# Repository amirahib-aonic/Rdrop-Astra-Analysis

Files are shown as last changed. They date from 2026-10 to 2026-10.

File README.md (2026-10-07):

# Rdrop Astra analysis

Three-stage illustrated evaluation: functional review, conservative refinement and complete redesign.

Website: https://amirahib-aonic.github.io/Rdrop-Astra-Analysis/

The four HTML pages use assets/, sources/ and downloads/. Original individual reports are retained in GPT6 Refined/Comparison/ and GPT6 New/Report/.

Hardware files are prototype evidence; automated design checks do not establish flight, functional or thermal qualification.

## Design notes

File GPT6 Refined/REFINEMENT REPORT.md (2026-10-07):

# Rdrop Astra — GPT6 refinement

6 October 2026 • KiCad 9.0.7 • Two copper layers • 1 oz copper target

This is a conservative copper and routing refinement for comparison with the original design. It is **not a verified 15 A / 18S thermal qualification**. The original project in `PCB Design` is unchanged. Open `hw-aonic-r-drop-main-board.kicad_pro` in this folder for the refined design.

## Delivered comparison views

- [Top copper comparison](Comparison/comparison-top.png)
- [Bottom copper comparison](Comparison/comparison-bottom.png) — both shown from above, without mirroring, to make coordinates directly comparable.
- [3D comparison](Comparison/comparison-3d.png)
- [Comparison gallery](Comparison/comparison.html)

Individual PNGs and vector SVGs are included. The images use the same layers, viewpoint, and scale for both designs. 3D views use the existing component models; they are not enclosure-fit or thermal simulations.

## Changes made

| Change | Original | Refined | Reason |
|---|---:|---:|---|
| Main top and bottom GND fill clearance | 0.8 mm | 0.3 mm | Recover ground copper around low-voltage traces and reduce wide return-path gaps. |
| Ground stitching vias | 299 total board vias | 339 total board vias | Add 40 GND vias, 0.8 mm diameter / 0.4 mm drill, in the low-voltage area with copper on both sides. |
| +5V_1 routing | 1.0 mm | 1.5 mm on 12 segments / 77.04 mm | Increase copper cross-section where existing clearances permit. |
| +5V_2 routing | 1.0 mm | 1.5 mm on 6 segments / 27.60 mm | Increase copper cross-section where existing clearances permit. |
| +UBEC_OUT routing | 0.8 mm | 1.2 mm on 4 segments / 9.22 mm | Increase copper cross-section on unconstrained segments. |
| J301 pad 1, GND | Inherited thermal connection | Solid zone connection | Remove an isolated thermal-spoke condition after refilling and give this supply-return pad a direct copper connection. Soldering heat demand increases. |

Seven proposed width increases were rejected after DRC and restored to their original widths. There is no claim that the whole supply path is now 1.5 mm wide. The remaining narrow sections, vias, pads, connectors, and protection parts can still limit current.

The battery-positive zone geometry, its 1.0 mm zone clearance, and its solid pad connections were retained. The dedicated servo-return and current-shunt nets remain separate from GND. USB and CAN signal routing, component placement, antenna keepout, and existing fabrication rules were retained. No components were added or removed; the additions are vias.

## Verification

| Check | Original | Refined |
|---|---:|---:|
| DRC errors | 0 | 0 |
| DRC warnings | 80 | 80 |
| Unconnected items | 0 | 0 |
| Schematic-parity issues | 0 | 0 |
| Footprints, including mounting holes and logos | 78 | 78 |
| Copper layers | 2 | 2 |
| GND filled area, top | 6140.37 mm² | 6876.47 mm² (+12.0%) |
| GND filled area, bottom | 6822.95 mm² | 7399.30 mm² (+8.4%) |

Exact checks verified unchanged footprint identities, values, positions, rotations, sides, pad coordinates, pad sizes, drill sizes, and net assignments. Board outline and cutout geometry are unchanged. All schematic files are byte-identical. The original PCB's SHA-256 remains `c80d10d69f5310de7cd80b0fb0a269ae44d5f7d4dcedefd1dde41fcfe5b25da2`.

The 80 existing warnings comprise 5 footprint-library issues, 40 library mismatches, 4 padstack warnings, 3 silk-edge clearance warnings, 3 silk-over-copper warnings, 10 silk overlaps, 14 text-height warnings, and 1 text-thickness warning. The fuse-pad negative paste margins were retained; they may reflect manual assembly, but that intent has not been confirmed.

Ground area is calculated from KiCad filled polygons, not an electrical performance measurement. No EMI, impedance, voltage-drop, temperature, or functional bench measurements were performed. DRC verifies the configured rules, not suitability of those rules for every operating environment.

## Outstanding current and voltage requirements

The supplied target is 15 A peak, up to an 18S battery, and 15–18 °C maximum temperature rise. Still needed:

1. The exact 15 A path: battery input, servo output, or another connection.
2. Normal current, peak duration, and repetition rate.
3. Confirm the maximum pack voltage: 18 × 4.2 V = 75.6 V if these are 4.2 V cells, versus the stated approximately 72–74 V.

These details are needed before selecting or validating current-carrying neck widths and interpreting the thermal target. Ambient temperature, enclosure cooling, and actual finished copper thickness will also affect measured temperature rise. Retaining the components means their current, voltage, pulse, and power ratings must be considered separately from copper geometry.

## How to compare hardware performance

Use identical assembly, firmware, load waveform, wiring, enclosure, and ambient conditions on both revisions. Measure supply drop and temperature at the same terminals, connectors, fuse/shunt pads, narrow copper sections, and vias. Check current-sense offset/noise, sensor readings, and communication reliability under the same load transitions. A before/after improvement requires those measurements; visual copper changes alone do not establish it.

## Method and records

The board was edited and refilled through the installed KiCad 9.0.7 Python board engine, checked with KiCad 9's DRC and schematic-parity checker, opened for visual review in the KiCad 9 PCB Editor, and rendered with KiCad 9. This was not a mouse-only editing run. `Comparison/changes.json` identifies accepted and rejected edits by UUID; `verification.json` records invariants, counts, areas, and hashes. The scripts document the process; rerunning the initial trial script replaces the refined board with the initial trial, so they are evidence rather than a one-click final-build command.

Ground-return rationale: [TI, PCB trace as a wave guide](https://www.ti.com/video/6307562268112) and [TI, optimizing PCB design for EMC](https://www.ti.com/video/6173428079001). Tool reference: [KiCad 9 zone filler](https://docs.kicad.org/doxygen-python-9.0/classpcbnew_1_1ZONE__FILLER.html).

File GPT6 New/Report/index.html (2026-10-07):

Hardware design report · Revision A · 06 October 2026

# One board. Two supply choices.

A complete two-layer ESP32 controller for the Rdrop drone attachment, preserving the original outline, cutout, mounting centers, magnetic sensor center and optical pad positions.

Prototype handoff · electrical checks passed

KiCad projectFabrication pack ↓

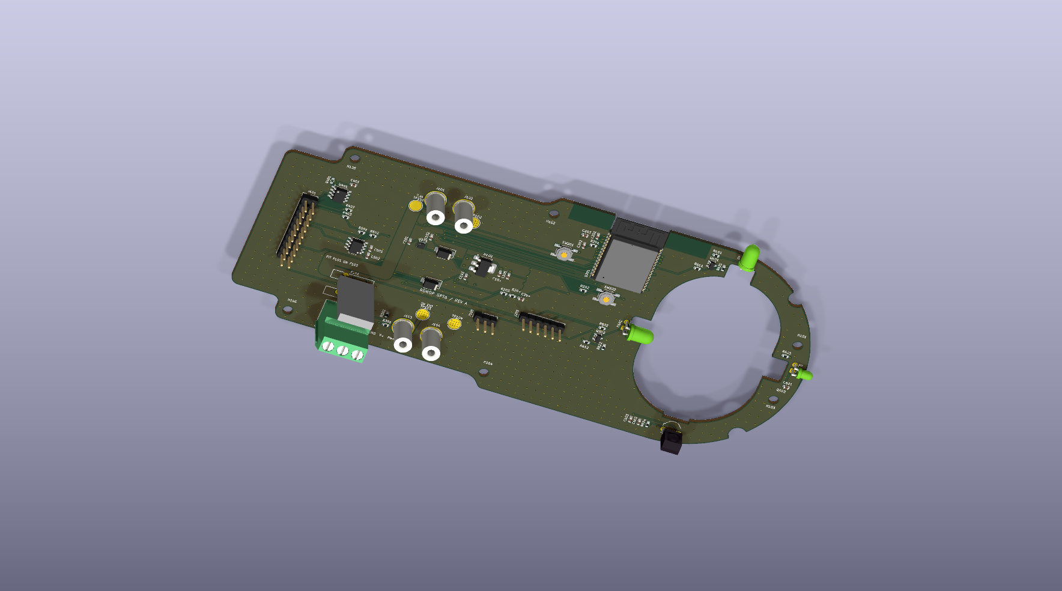
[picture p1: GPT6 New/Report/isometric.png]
Actual KiCad 3D rendering of the Rdrop redesigned PCB


Actual KiCad model · variant A · fuse shown as a conservative body envelope.

0ERC violations

0DRC errors / unrouted nets

2 ozCopper on each of two layers

69Footprints, including board features

The selected protection takes priority over pulse endurance. MF-RG900-0 has 9 A hold and 15.3 A trip specifications at 23 °C. It may interrupt the requested 15 A / 30 second servo pulse. Its trip is thermal and depends on ambient temperature, mounting, load history and airflow. This is the protection option you selected; successful pulse endurance is not guaranteed.

01 / System

## The original functions, rebuilt.

Six functional sheets plus a system sheet. On-board inputs are regulated 7.4 V and 5 V only; a 14–18S battery must stay upstream of an appropriately rated external regulator.

### Logic power

TLV76750DRVR converts 7.4 V to 5 V for logic. Two SS14 diodes combine that output and external 5 V. TLV1117LV33DCYR supplies 3.3 V with ceramic 0603 input/output decoupling.

The AMS1117 alternative remains an LDO, not a switching step-down regulator. TLV1117LV was selected for ceramic-capacitor stability.

### Control & position

ESP32-WROOM-32E-N4, UART programming, boot/reset buttons, voltage sensing and a 20-pin interface. AS5600-ASOM operates at 3.3 V with 4.7 kΩ I²C pull-ups; its magnetic center is retained.

### Dual optical gates

Two TSAL6200 emitters with individual 2N7002P drivers. TEFT4300 supplies an analog beam signal; TSSP4038 supplies a 38 kHz demodulated digital signal. Original footprint origins and optical pad centers are preserved.

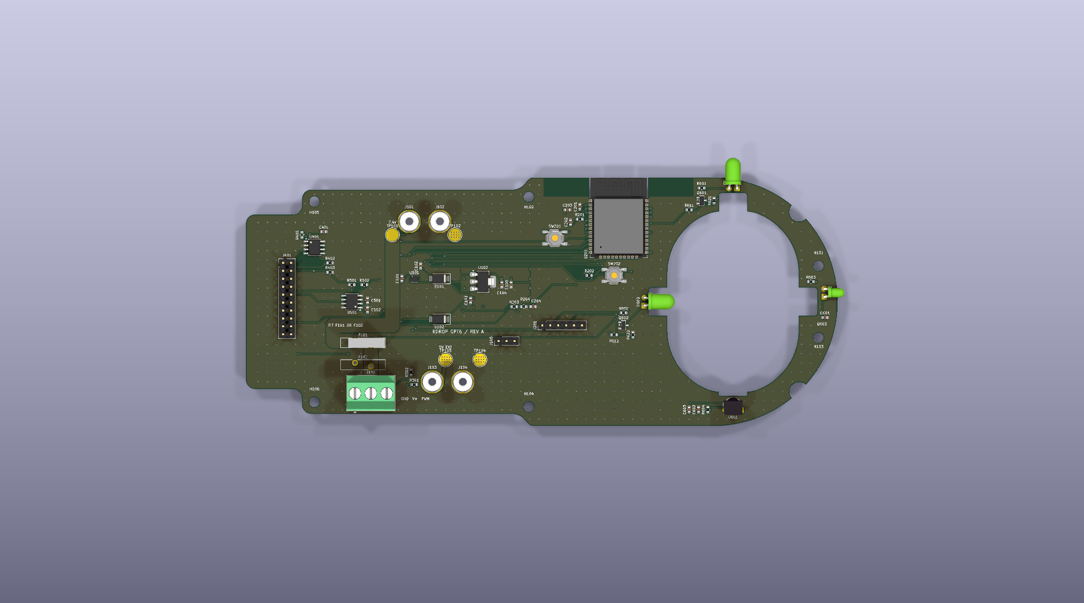
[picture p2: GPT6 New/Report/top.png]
Top view of assembled PCB


Top view · standard component bodies, preserved cutout.

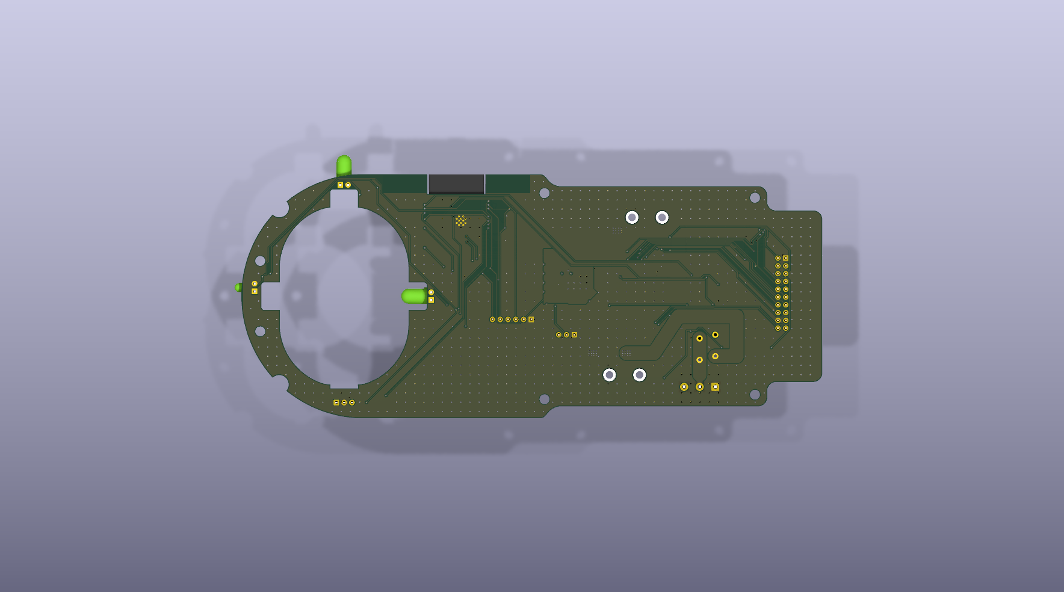
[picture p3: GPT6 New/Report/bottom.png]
Bottom view of PCB


Bottom view · ground fill and copper routing.

02 / Power engineering

## Servo current bypasses the logic regulators.

External regulated source→F101 · 7.4 V→J106 · servo

Explore assembly choice:

Fit F101 and leave F102 empty. The servo receives external 7.4 V.

### Copper & transitions

The incoming servo bus is 4.5 mm wide. The fused output uses both layers; its final connector approach uses 2 mm traces on each face. The return has 3 mm traces on each face and ground pours. The external 5 V input changes layers through a 12-via array inside TP103; both ground wire pads also have 12-via arrays.

For 70 µm copper, a 4.5 mm × 70 mm bus has approximately 3.8 mΩ resistance at 20 °C before solder joints and component resistance. At 15 A this segment dissipates approximately 0.86 W. This is a resistance estimate, not a validated temperature-rise result.

J106 is Phoenix Contact 1711738, nominal 24 A. Use appropriate wire gauge, screw torque and strain relief. The small 2.54 mm monitoring/programming headers are not servo power connectors.

### Thermal boundary

At 7 A the fuse's specified initial maximum 9.2 mΩ resistance produces about 0.45 W; at 15 A it produces about 2.07 W before its resistance rises. Post-trip resistance can be higher.

MF-RG900 hold current derates to 7.2 A at 50 °C and 6.4 A at 60 °C. A 7 A load therefore has little margin in a hot enclosure. Check the fuse at actual ambient and duty cycle.

At 8.4 V input and 0.5 A logic load, the 7.4 V→5 V LDO dissipates 1.7 W. The 3.3 V LDO dissipates roughly 0.6–0.7 W after the diode. Ground thermal vias and a 22 × 18 mm two-face 3.3 V cooling area are provided. Sustained full-load operation needs temperature measurement; design around ≤250 mA average logic current until tested.

External regulator selection matters. The named UBEC-10A-HV(3–14S)-V1 is rated for up to 14S, so it must not be connected to an 18S pack. Hobbywing's 25 A HV family supports 3–18S and 7.4 V output; confirm the exact purchased model and pulse rating. An unspecified APM 5 V output must be treated as a logic supply until its 7 A continuous / 15 A for 30 seconds capability is established.

Assembly and input limits

Never fit both F101 and F102: that joins the external 5 V and 7.4 V sources. The on-board 5 V LDO is for logic only and does not supply servo current. TP101/TP102 accept the regulated 7.4 V pair; TP103/TP104 accept the external 5 V pair. Retained conductive standoffs are mechanical/regulator interfaces; their manufacturer does not specify a 15 A electrical rating, so use the dedicated wire pads for servo supply current. Connect no raw battery voltage, and verify polarity before energizing.

J105 = GND / 7.4 V monitoring / unused. J201 and J401 expose low-current 3.3 V monitoring only; budget external loads separately. No reverse-polarity, overvoltage, or flyback-energy qualification has been completed. Measure servo rail transients and use external clamping or regulator output capacitance if its specification requires it.

03 / Integration

## Pin maps you can build against.

### ESP32 GPIO

GPIO | Function | Connection
23 | Servo PWM | J106 via R301
32 | IR TX 1 | D601 / 38 kHz
33 | IR TX 2 | D602 / 38 kHz
34 | Analog beam | TEFT4300; input only
35 | Digital beam | TSSP4038; input only
21 | I²C SDA | AS5600
22 | I²C SCL | AS5600
16 | CAN RX | SN65HVD230
17 | CAN TX | SN65HVD230
18 | FC arm | 100 kΩ pull-down
19 | FC command | 100 kΩ pull-down
25 | FC feedback | 3.3 V output
36 | Regulator sense | 100 kΩ / 33 kΩ divider

### J401 · 20-pin interface

Pin | Signal
1 | GND
2 | V3P3
3 | FC_ARM
4 | FC_COMMAND
5 | FC_FEED
6 | PWM_MCU
7 | CAN_H
8 | CAN_L
9 | SDA
10 | SCL
11 | GPIO4
12 | GPIO5
13 | GPIO13
14 | GPIO14
15 | GPIO26
16 | GPIO27
17 | REG_SENSE
18 | GND
19 | UART_TX
20 | UART_RX

Firmware and commissioning requirements

Drive both IR emitters with independent 38 kHz modulation. The 220 Ω emitter resistors set approximately 9 mA peak current at 3.3 V; verify optical margin under sunlight and motor interference. TEFT4300's 10 kΩ / 100 nF collector circuit averages the modulation with a 1 ms time constant, so use a calibrated analog threshold. GPIO34/35/36 are input-only. Read AS5600 at I²C address 0x36 and verify magnet status and the angle direction mechanically.

The analog voltage divider reports approximately 2.08 V at an 8.4 V input. Calibrate ADC attenuation and reference; do not apply raw pack voltage. CAN is non-isolated and requires a shared signal ground. R401 is DNP unless this node terminates the bus. GPIO5 is a strap pin: avoid external drive that changes its boot state. Boot uses GPIO0; hold BOOT while resetting for download.

Set servo and IR outputs low at startup. A hardware servo PWM pull-down is provided; firmware must require an explicit valid armed state before motion, debounce sensors, detect timeouts and fail safely on reset or communication loss. Firmware is not included or validated in this hardware package.

04 / Evidence

## Checked geometry. Explicit qualification limits.

### Electrical

ERC: 0 violations.
DRC: 0 errors.
Unconnected nets: 0.
Schematic parity conflicts: 0.

ERC result ↓
DRC result ↓

Four library comparison warnings remain for deliberately tailored silkscreen graphics on U201, D601, D602 and Q603. All standard pad geometry is unchanged.

### Mechanical & library audit

Original edge and cutout geometry: exact match.
All six M3 mounting centers: retained.
All standard R/C: 0603.
All standard footprint IDs: resolved.
All 3D model references: resolved.

Machine-readable audit ↓

Nominal outline bounds: 189.580 × 79.742 mm. Custom optical lead forming and installed clearances still need checking.

### Manufacturing outputs

Nine Gerber layers, separate plated/non-plated Excellon drill files, drill maps, assembly variants, BOMs, placement data, a seven-page schematic PDF, STEP and GLB models.

KiCad 10.0.5 generated the outputs. Standard IR diode models have generic colors. Fuse envelope: 14 × 3 × 21.7 mm body, 2 mm board standoff allowance; leads are omitted.

Prototype test plan — required before operation

1. Unpowered inspection: verify one fitted fuse, connector polarity, isolation between 5 V and 7.4 V, solder joints, and optical lead orientation.
2. Power with a current-limited bench source, first on 5 V and then 7.4 V. Check 3.3 V, reset, programming and ADC scaling without a servo.
3. Measure supply stability during ESP32 radio traffic and servo motion. Scope 3.3 V and servo input during turn-on, braking and current steps; verify the external regulator remains in specification.
4. Apply 5 A, 7 A, then the specified 15 A / 30 second load with an electronic load or representative servo. Record fuse trip time, voltage drop, connector and copper temperatures. A trip during the pulse may be consistent with the chosen fuse target.
5. Repeat in the actual enclosure at the highest ambient and intended airflow. Verify LDO junction margin using package temperature and manufacturer thermal data; check protection recovery after a trip.
6. Test magnetic sensing across full rotation and verify beam detection with ambient light, vibration, motor noise and real bait. Check reset, lost-command and blocked-mechanism behavior with an unloaded attachment before flight.

05 / Procurement

## Exact parts, searchable.

BOM A fits the 7.4 V fuse; BOM B fits the 5 V fuse. Supply-chain links below are exact-MPN searches, not a guarantee of current inventory. Pads and mounting holes are board features rather than purchased parts.

Reference | Value | Exact MPN | Manufacturer | Fit A / B

06 / Deliverables

## Everything stays in GPT6 New.

### Design

KiCad project
System schematic
Routed PCB
Schematic PDF

### Fabrication & assembly

Gerbers + drills + notes ZIP
BOM A / 7.4 V
BOM B / 5 V
SMD placement
Assembly instructions

### Mechanical

Assembled STEP
Assembled GLB
Variant B STEP
Complete project ZIP

Primary references

## Manufacturer evidence.

ESP32-WROOM-32E ↗ (https://documentation.espressif.com/esp32-wroom-32e_esp32-wroom-32ue_datasheet_en.html)TLV767 LDO ↗ (https://www.ti.com/lit/ds/symlink/tlv767.pdf)TLV1117LV LDO ↗ (https://www.ti.com/lit/ds/symlink/tlv1117lv.pdf)AS5600 ↗ (https://look.ams-osram.com/m/7059eac7531a86fd/original/AS5600-DS000365.pdf)MF-RG fuse series ↗ (https://www.bourns.com/docs/product-datasheets/mf-rg.pdf)TSAL6200 ↗ (https://www.vishay.com/en/product/81010/)TEFT4300 ↗ (https://www.vishay.com/docs/81549/teft4300.pdf)TSSP4038 ↗ (https://www.vishay.com/docs/82458/tssp40.pdf)Servo terminal 1711738 ↗ (https://www.phoenixcontact.com/en-us/products/printed-circuit-board-terminal-mkds-3-3-508-1711738)Wurth standoff ↗ (https://www.we-online.com/components/products/datasheet/9774100360R.pdf)Hobbywing 10 A HV ↗ (https://www.hobbywingdirect.com/products/ubec-10a-hv-3s-14s)Hobbywing 25 A HV / 18S ↗ (https://www.hobbywing.com/en/uploads/file/20221108/12f5024346c4952abc96da8c0f2ffc32.pdf)

Rdrop GPT6 · Rev A · Local design report · Prototype engineering handoff. Electrical rule checks do not establish thermal, optical, EMC or flight qualification. The original project is preserved.

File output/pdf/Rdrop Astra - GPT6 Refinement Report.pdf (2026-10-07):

RDROP ASTRA | GPT6 REFINEMENT | 6 OCTOBER 2026 | 1

# Rdrop Astra - GPT6 refinement

6 October 2026 • KiCad 9.0.7 • Two copper layers • 1 oz copper target

This is a conservative copper and routing refinement for comparison with the original design. It is not a verified 15 A / 18S thermal qualification. The original project in PCB Design is unchanged. Open hw-aonic-r-drop-main-board.kicad_pro in this folder for the refined design.

## Delivered comparison views

- Top copper comparison
- Bottom copper comparison - both shown from above, without mirroring, to make coordinates directly comparable.
- 3D comparison
- Comparison gallery

Individual PNGs and vector SVGs are included. The images use the same layers, viewpoint, and scale for both designs. 3D views use the existing component models; they are not enclosure-fit or thermal simulations.

## Changes made

Change | Original | Refined | Reason
Main top and bottom GND fill clearance | 0.8 mm | 0.3 mm | Recover ground copper around low-voltage traces and reduce wide return-path gaps.
Ground stitching vias | 299 total board vias | 339 total board vias | Add 40 GND vias, 0.8 mm diameter / 0.4 mm drill, in the low-voltage area with copper on both sides.
+5V_1 routing | 1.0 mm | 1.5 mm on 12 segments / 77.04 mm | Increase copper cross-section where existing clearances permit.
+5V_2 routing | 1.0 mm | 1.5 mm on 6 segments / 27.60 mm | Increase copper cross-section where existing clearances permit.
+UBEC_OUT routing | 0.8 mm | 1.2 mm on 4 segments / 9.22 mm | Increase copper cross-section on unconstrained segments.
J301 pad 1, GND | Inherited thermal connection | Solid zone connection | Remove an isolated thermal-spoke condition after refilling and give this supply-return pad a direct copper connection. Soldering heat demand increases.

Seven proposed width increases were rejected after DRC and restored to their original widths. There is no claim that the whole supply path is now 1.5 mm wide. The remaining narrow sections, vias, pads, connectors, and protection parts can still limit current.

The battery-positive zone geometry, its 1.0 mm zone clearance, and its solid pad connections were retained. The dedicated servo-return and current-shunt nets remain separate from GND. USB and CAN signal routing, component placement, antenna keepout, and existing fabrication rules were retained. No components were added or removed; the additions are vias.

## Verification

Check | Original | Refined
DRC errors | 0 | 0
DRC warnings | 80 | 80
Unconnected items | 0 | 0
Schematic-parity issues | 0 | 0
Footprints, including mounting holes and logos | 78 | 78
Copper layers | 2 | 2
GND filled area, top | 6140.37 mm² | 6876.47 mm² (+12.0%)
GND filled area, bottom | 6822.95 mm² | 7399.30 mm² (+8.4%)

Exact checks verified unchanged footprint identities, values, positions, rotations, sides, pad coordinates, pad sizes, drill sizes, and net assignments. Board outline and cutout geometry are unchanged. All schematic files are byte-identical. The original PCB's SHA-256 remains c80d10d69f5310de7cd80b0fb0a269ae44d5f7d4dcedefd1dde41fcfe5b25da2.

The 80 existing warnings comprise 5 footprint-library issues, 40 library mismatches, 4 padstack warnings, 3 silk-edge clearance warnings, 3 silk-over-copper warnings, 10 silk overlaps, 14 text-height warnings, and 1 text-thickness warning. The fuse-pad negative paste margins were retained; they may reflect manual assembly, but that intent has not been confirmed.

Ground area is calculated from KiCad filled polygons, not an electrical performance measurement. No EMI, impedance, voltage-drop, temperature, or functional bench measurements were performed. DRC verifies the configured rules, not suitability of those rules for every operating environment.

## Outstanding current and voltage requirements

The supplied target is 15 A peak, up to an 18S battery, and 15-18 °C maximum temperature rise. Still needed:

1. The exact 15 A path: battery input, servo output, or another connection.
2. Normal current, peak duration, and repetition rate.
3. Confirm the maximum pack voltage: 18 × 4.2 V = 75.6 V if these are 4.2 V cells, versus the stated approximately 72-74 V.

These details are needed before selecting or validating current-carrying neck widths and interpreting the thermal target. Ambient temperature, enclosure cooling, and actual finished copper thickness will also affect measured temperature rise. Retaining the components means their current, voltage, pulse, and power ratings must be considered separately from copper geometry.

## How to compare hardware performance

Use identical assembly, firmware, load waveform, wiring, enclosure, and ambient conditions on both revisions. Measure supply drop and temperature at the same terminals, connectors, fuse/shunt pads, narrow copper sections, and vias. Check current-sense offset/noise, sensor readings, and communication reliability under the same load transitions. A before/after improvement requires those measurements; visual copper changes alone do not establish it.

## Method and records

The board was edited and refilled through the installed KiCad 9.0.7 Python board engine, checked with KiCad 9's DRC and schematic-parity checker, opened for visual review in the KiCad 9 PCB Editor, and rendered with KiCad 9. This was not a mouse-only editing run. Comparison/changes.json identifies accepted and rejected edits by UUID; verification.json records invariants, counts, areas, and hashes. The scripts document the process; rerunning the initial trial script replaces the refined board with the initial trial, so they are evidence rather than a one-click final-build command.

Ground-return rationale: TI, PCB trace as a wave guide (https://www.ti.com/video/6307562268112) and TI, optimizing PCB design for EMC. (https://www.ti.com/video/6173428079001) Tool reference: KiCad 9 zone filler. (https://docs.kicad.org/doxygen-python-9.0/classpcbnew_1_1ZONE__FILLER.html)

# Top copper and silkscreen

## Original

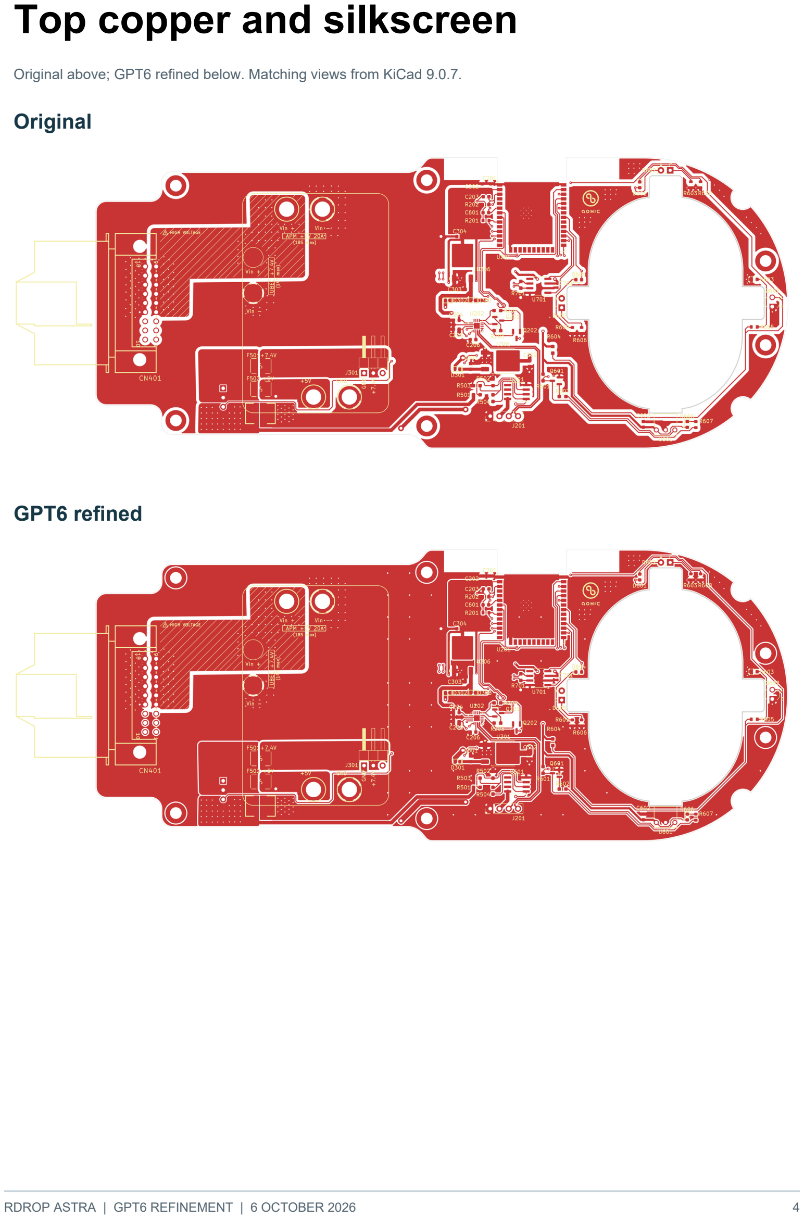
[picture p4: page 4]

Original above; GPT6 refined below. Matching views from KiCad 9.0.7.

## GPT6 refined

# Bottom copper and silkscreen

## Original

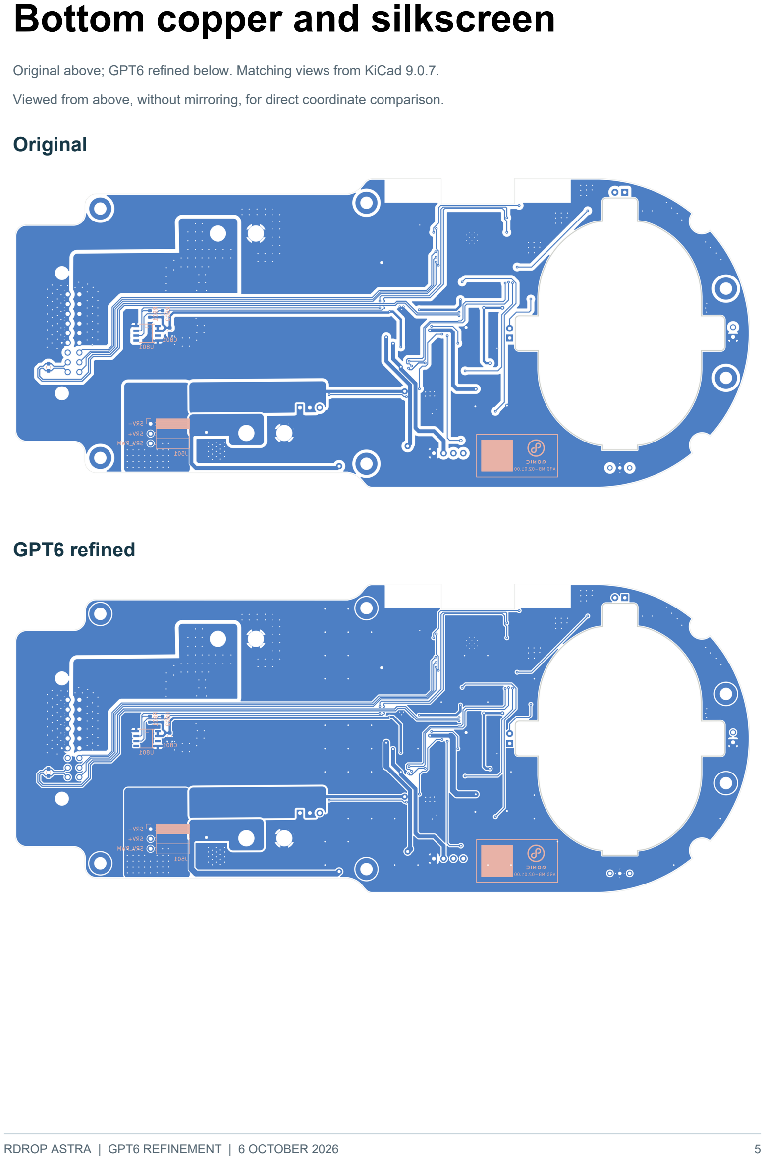
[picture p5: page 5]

Original above; GPT6 refined below. Matching views from KiCad 9.0.7.

Viewed from above, without mirroring, for direct coordinate comparison.

## GPT6 refined

# 3D layout comparison

## Original

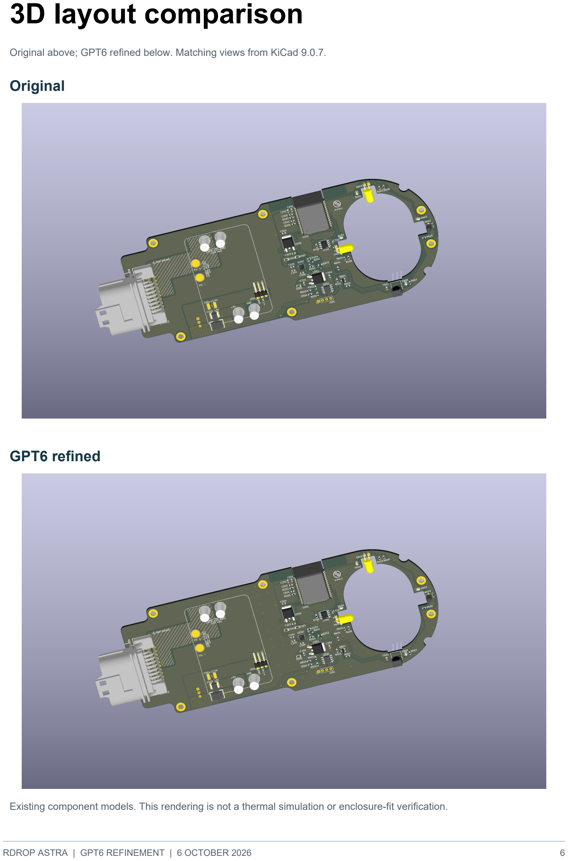
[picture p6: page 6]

Original above; GPT6 refined below. Matching views from KiCad 9.0.7.

## GPT6 refined

Existing component models. This rendering is not a thermal simulation or enclosure-fit verification.

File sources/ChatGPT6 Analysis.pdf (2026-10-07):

## Method and objective:

Have GPT6 review existing design and output list of recommended changes. We verify and implement changes accordingly. To see what errors and potential functionality risks might have been overlooked.

1.

Have GPT6 edit latest updated design (after step 1) on KiCAD, to see what sort of improvements it would implement, and the quality of its execution

2.

Have GPT6 completely redesign the Rdrop board based on provided description of project requirements and limitations, and generate fabrication files. To see how effective it is in generating a project from scratch.

3.

## Prompts:

Step 1 The Rdrop project is a rat bait dropping device that can be attached to the bottom of the drone. 2 pairs of IR transmitter and receiver are used in my current set up, one digital and one analog-based. My constraints are as follows:
- As in the Butiks (1).DXF file, that is the bottom mechanism (where the turning gears are placed etc), above which will sit the bottom of the PCB.
- As you can access in the current rdrop PCB file, the edge cuts are according to the size constraints of the top casing/cover of the device that it would be mounted on. There is a hole that have followed the sizing of the larger of 2 rat bait types that the project would use and the hole would allow the bait to fall through and the IR sensors would work accordingly.
- The finalised connector that would connect to the drone is the JAE MX23A type (18pin standard) which would bring across the drone battery voltage that would be stepped down through either an APM (Aonic Power Module) or an external, solderable UBEC regulator. It serves the feature of Selectable servo input voltage (+7.4V / +5V) - Servo input voltage is now configurable from the drone battery input via one of two regulator/fuse paths:
- For the APM: 18S / 78V would be stepped down to 5V and then go to the respective paths and the 5V would also feed +5V directly to the servo feed (SRV+)
- For the UBEC: drone battery voltage would be stepped down to 7.4V and then into LM1084-5.0 Regulator (APM power path would bypass this).
- The rdrop board is targetted to carry at least 15A of current, taking into account current spikes when using the servo that could reach up to 7A when 7.4V is used to feed it. Taking into account miscellaneous board component usage that had been surveyed to be up to 2-3A max at normal operation usage.
Going through the files i've given you access to, and permission to scour the web for the relevant datasheets of the component, understand my design, and verify whether it would serve my intended design and functionality accordingly. Otherwise, list all the corrections I would need to do, direct reason as to why it is wrong and why your correction is right, and also listing any parts that might need flagging, if any. My aim is to have a functional board first, any refinement we discuss later. Estimate as well with my set up and in your recommended corrections, the current consumption of the board overall, and break down for each component based on their data sheet. Do not edit the original files but instead create a duplicate adjacent file and edit there
Step 2 Now, i want to evaluate performance of gpt6 in editing and refining pcb on its own, and compare with the design that i have. In the given Rdrop Astra folder, edit my pcb on how you would refine its layout, and traces and planes, adhering to schematic and functionality by making a new folder in the Rdrop Astra folder called "GPT6 Refined", copy the relevant kicad files and make edits via kicad 9 on the computer. . and generate the references images with pcb layout and 3 layout compared to the original one. list the changes made.. Ask me any information you might need to know on the target specs etc for this 2 layer 1oz board. board sizing 15A support. Maintain the shape and cutout and the components. Positions of magnetic sensor, IR transmitter and receivers must also remain. The mounted connectors must also remain in their positions.
Step 3 Act as an expert hardware engineer. Redesign a complete 2-layer PCB project for this Rdrop project, from schematic to pcb to 3d model and fabrication files, for an ESP32 wroom 32e-based rat bait drop attachment to a drone. Include the functional blocks such as in the original Rdrop design: (1) 7.4V to 5V LDO, 5V to 3.3V step-down regulator using an AMS1117 with input/output decoupling caps, (2) ESP32-WROOM-32 module, (3) AS5600 magnetic sensor (4) 1 pair of TSAL6200 and TEFT4300 and 1 more pair of TSAL6200 and TSSP4038, a mini mum 16 pin connector, board must support up to 15A, a 3pin servo connector with 2 fuses (1 soldered at a time) that trips at 15A, to deliver either 7.4 V or 5V to the servo. standoffs and UBEC input pad (regulator wires would be soldered onto them) must remain for the external regulator choices (must also have a 3pin header for UBEC output). You may experiment with any better alternatives of the components apart from the ones that had been selected in the previous design.
Use exact component part numbers available in standard supply chains (e.g., DigiKey/LCSC). Use 0603 size for all standard resistors and capacitors. Ensure all components have valid, standard KiCad library footprints assigned to prevent schematic-to-layout parity errors
The finished board must be within the outline size and cutout of the original, with mounting holes at the corner. Open KiCad, generate the multi-sheet schematic, perform component placement, and route all copper traces. Run both Electrical Rule Check (ERC) and Design Rule Check (DRC) iteratively until zero errors or unresolved net parity conflicts remain. Export the final Gerber files, Excellon drill files, BOM, and CPL (pick-and-place) data. Save and organise files into a new folder in the Rdrop Astra folder called "GPT6 New" Generate also a report of your new design (website form)

## Findings:

Step | GPT6 Output | Actions/Comments
| | Recommendation/Risk highlighted | Action taken after verifying?
| | 1)UBEC Max 14S | No action. Acknowledged, as the UBEC would only be used for 14S drone batteries
| | 2) Make the 5 V / 7.4 V selection mutually exclusive | No action. This has been considered in design and usage, where only one of the fuses would be soldered on at a time, depending on which power regulator is used. Additionally there are Schottky diodes in place to protect from backflow of current.
| | 3) Replace the servo shunt and redesign the current measurement | Action: Shunt and resistor values have been updated.
| | 4)Qualify the entire 15 A path, including fuses and connectors | Action: Quick run through and double check. Fuse can handle expected current draw, J1 and J2 plane size supports 15A, standoffs are 3 0A rated, JAE double checked its suitability.
| | 5) Connect AS5600 correctly and add I²C pull-ups | Action: 5V shorted accordingly and added pull-ups to I²C SDA SCL
| | 6)Drive the IR emitters independently of the visible LEDs | Action: Circuit changed from series to parallel

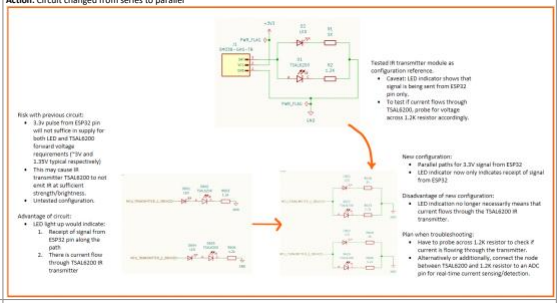
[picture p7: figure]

| | 7) Action: Moved LED to near Q601 Remove the heavy load on the TSSP4038 output •
| | 8) Make the analog IR node a sensor input rather than an indicator driver | No action. TEFT4300 circuit has been revisited extensively and the current setup has been tested and can function as intended.
| | 9) Fit only the CAN termination required by the installed bus | Action: R702 removed and marked as DNP (Do Not Populate) but remain in cases where the other device does not have its own built in CA N termination resistor
| | 10) Establish regulator stability, headroom and enclosed thermal performance | No action. This is a refined verification and time constraints to not permit it, but regulator choice had been reviewed and approved by Senior Embedded Engineer previously.
| | 11)Isolate programming USB power and confirm controlsignal levels | No action. Passed previous review.
| | 12) Complete the raw-battery protection and insulation review | No action. Passed previous review and such concern was not raised then. This is an added layer of security, where the planes are designe d to support current expected, and fuse is present at critical points of power draw elsewhere.
| | Review, analyze and comment on changes made Comments from Change Report, Detailed Changes and Verification Records pdf:

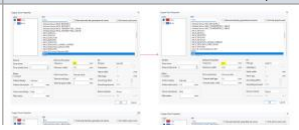
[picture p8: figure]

Change made | Comment | Screen capture of change
Step 1 Review file that contains list of recommended
changes

READ_ME_
REVIEW
Step 2 Website generated
containing PCB layouts
and 3D comparison

•

Detailed change report
(.md and pdf)

Rdrop Astra
- GPT6 Re...

•

•

Verification Records

Rdrop Astra
- Verificat...

•

•

GND clearance expansion Good that it reduces conservativity of previous clearance, to expand return path and remove isolated thermal-spokes

# ChatGPT6 Analysis

Monday, 5 October, 2026 4:44 PM

JEE Work Notes Page 1

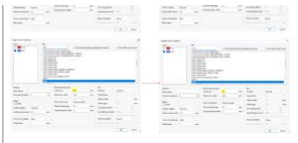
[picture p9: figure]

Rdrop Astra
- Verificat...

•

Detailed Changes

Rdrop Astra
- Detailed...

•

•

"GPT6 Refined" folder of
copied and edited KiCAD
project files

•

GND stitching vias | Quite random placement even over serial barcode region, but good initiative to stitch wide via-less areas of top and bottom copper pours
+5V_1, +5V_2 and +UBEC_OUT trace expansion | Good initiative but expansions were mid-trace, abrupt (no taper although low risk of acid traps), and not throughout the entire trace. Initially 1mm considered to suffice for 5V delivery with relatively low power draw

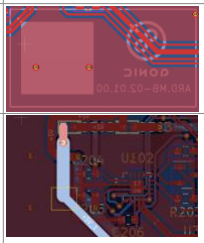
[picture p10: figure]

Overall comment: Changes are minimal, conservative and only in copper pour/trace sizing and relief. Good initiatives especially on taking liberty with GND pour clearances, but execution can be more complete (inconsistent track size) and thoughtful (via placement). Careful in implementing changes of which verification method and records are provided. No changes or optimizations in component and track placements.

Step 3 Website detailing new design

Comments at a glance:
•Needs extensive validation of circuit and inter-circuit design and functionality, and component placement.
•Good tracing at some parts (straight one-way horizontal traces on top copper), but some parts are clearly wonky most likely due to the walkaround feature used

○

•Good added layers of gates to improve logic efficiency e.g. individual drivers for IR transmitters
- Placement of connectors requires more user-provided constraint and guidance so they are more sensible in terms of product integration, outcome and use
- Efficient use of space could be in place if it were free to design the shape (not constrained by existing board outline)
- Smaller BOM: The new Rdrop has 69 PCB footprints versus 78 in the original—9 fewer (about 12%), counting mounting holes, test points, and other board features.
- Schematic generated is not human-readable without extensive zooming

○

- PCB looks passable and decent and can be good with refinements
- Maximised via use which can be good
○No use of power planes - not so efficient but perhaps can be encouraged in prompt
- Instead, extremely large power traces were used (4.5mm) - unnecessarily overpowered, use planes instead to reduce loop inductance and noise

○

•Good that it can generate fabrication files too - can automate job
- It also generates harness/connection list which is an efficient to keep track of traces and troubleshoot in the future
- Could also look into git integration in workflow in future

JEE Work Notes Page 2

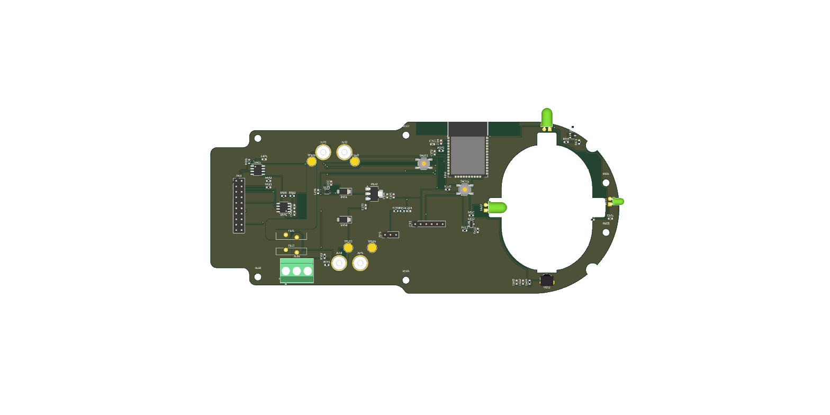
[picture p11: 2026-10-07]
GPT6 New/Report/placement.png

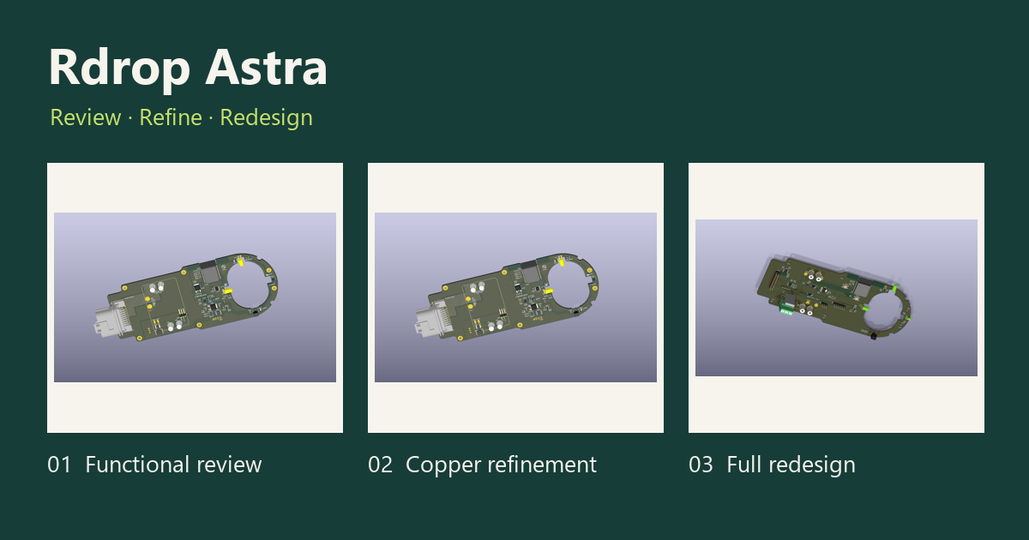
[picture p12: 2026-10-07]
assets/teams-preview.png

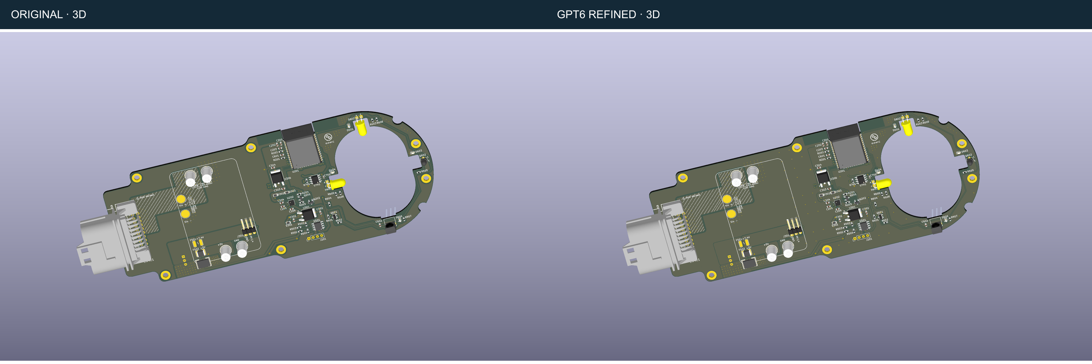
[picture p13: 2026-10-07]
assets/comparison-3d.png

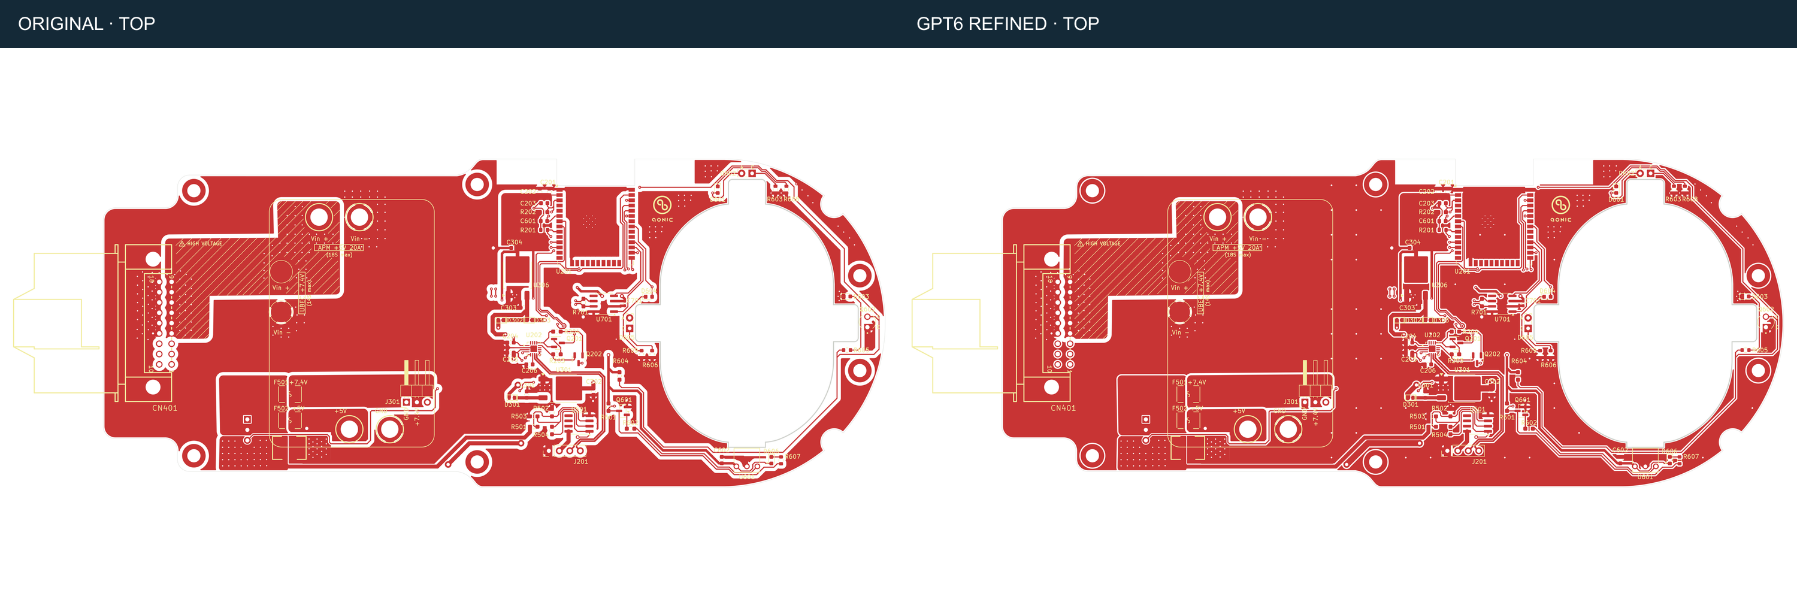
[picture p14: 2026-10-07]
assets/comparison-top.png

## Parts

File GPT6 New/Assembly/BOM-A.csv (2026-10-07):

References | Quantity | Value | MPN | Manufacturer | Footprint
J101,J102,J103,J104 | 4 | M3 REGULATOR STANDOFF | 9774100360R | Wurth Elektronik | Mounting_Wuerth:Mounting_Wuerth_WA-SMSI-M3_H10mm_9774100360
J105 | 1 | UBEC OUT MONITOR | TSW-103-07-G-S | Samtec | Connector_PinHeader_2.54mm:PinHeader_1x03_P2.54mm_Vertical
U101 | 1 | TLV76750DRVR | TLV76750DRVR | Texas Instruments | Package_SON:WSON-6-1EP_2x2mm_P0.65mm_EP1x1.6mm_ThermalVias
C101,C102,C103,C104,C105,C201 | 6 | 10uF | GRM188R61C106KAALD | Murata | Capacitor_SMD:C_0603_1608Metric
D101,D102 | 2 | SS14 | SS14-E3/61T | Vishay | Diode_SMD:D_SMA
U102 | 1 | TLV1117LV33DCYR | TLV1117LV33DCYR | Texas Instruments | Package_TO_SOT_SMD:SOT-223-3_TabPin2
F101 | 1 | MF-RG900-0 | MF-RG900-0 | Bourns | Fuse:Fuse_Bourns_MF-RG900
J106 | 1 | SERVO GND / V+ / PWM | 1711738 | Phoenix Contact | TerminalBlock_Phoenix:TerminalBlock_Phoenix_MKDS-3-3-5.08_1x03_P5.08mm_Horizontal
R301,R611,R612,R604 | 4 | 100 | RC0603FR-07100RL | Yageo | Resistor_SMD:R_0603_1608Metric
R302,R203,R402,R403,R621,R622 | 6 | 100k | RC0603FR-07100KL | Yageo | Resistor_SMD:R_0603_1608Metric
U201 | 1 | ESP32-WROOM-32E-N4 | ESP32-WROOM-32E-N4 | Espressif | RF_Module:ESP32-WROOM-32E
C202,C204,C401,C501,C601,C602 | 6 | 100nF | GRM188R71H104KA93D | Murata | Capacitor_SMD:C_0603_1608Metric
C203,C502,C603 | 3 | 1uF | GRM188R61E105KA12D | Murata | Capacitor_SMD:C_0603_1608Metric
R201,R202,R603 | 3 | 10k | RC0603FR-0710KL | Yageo | Resistor_SMD:R_0603_1608Metric
SW201,SW202 | 2 | RESET | TL3342F160QG | E-Switch | Button_Switch_SMD:SW_SPST_TL3342
J201 | 1 | UART PROGRAM | TSW-106-07-G-S | Samtec | Connector_PinHeader_2.54mm:PinHeader_1x06_P2.54mm_Vertical
R204 | 1 | 33k | RC0603FR-0733KL | Yageo | Resistor_SMD:R_0603_1608Metric
J401 | 1 | 20-PIN CONTROL | TSW-110-07-G-D | Samtec | Connector_PinHeader_2.54mm:PinHeader_2x10_P2.54mm_Vertical
U401 | 1 | SN65HVD230DR | SN65HVD230DR | Texas Instruments | Package_SO:SOIC-8_3.9x4.9mm_P1.27mm
U501 | 1 | AS5600-ASOM | AS5600-ASOM | ams OSRAM | Package_SO:SOIC-8_3.9x4.9mm_P1.27mm
R501,R502 | 2 | 4.7k | RC0603FR-074K7L | Yageo | Resistor_SMD:R_0603_1608Metric
D601,D602 | 2 | TSAL6200 | TSAL6200 | Vishay | LED_THT:LED_D5.0mm_Horizontal_O1.27mm_Z3.0mm
R601,R602 | 2 | 220 | RC0603FR-07220RL | Yageo | Resistor_SMD:R_0603_1608Metric
Q601,Q602 | 2 | 2N7002P,215 | 2N7002P,215 | Nexperia | Package_TO_SOT_SMD:SOT-23
Q603 | 1 | TEFT4300 | TEFT4300 | Vishay | LED_THT:LED_D3.0mm_Horizontal_O1.27mm_Z2.0mm
U601 | 1 | TSSP4038 | TSSP4038 | Vishay | OptoDevice:Vishay_MOLD-3Pin

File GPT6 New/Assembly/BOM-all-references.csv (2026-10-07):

Reference | Value | MPN | Manufacturer | Footprint | Fit_A | Fit_B | Procurement | Notes | Supplier_search
J101 | M3 REGULATOR STANDOFF | 9774100360R | Wurth Elektronik | Mounting_Wuerth:Mounting_Wuerth_WA-SMSI-M3_H10mm_9774100360 | YES | YES | PART | M3 SMT conductive standoff, 10 mm height; original mounting centers retained. Verify regulator height and mounting interface. | https://www.digikey.com/en/products/result?keywords=9774100360R
J102 | M3 REGULATOR STANDOFF | 9774100360R | Wurth Elektronik | Mounting_Wuerth:Mounting_Wuerth_WA-SMSI-M3_H10mm_9774100360 | YES | YES | PART | M3 SMT conductive standoff, 10 mm height; original mounting centers retained. Verify regulator height and mounting interface. | https://www.digikey.com/en/products/result?keywords=9774100360R
J103 | M3 REGULATOR STANDOFF | 9774100360R | Wurth Elektronik | Mounting_Wuerth:Mounting_Wuerth_WA-SMSI-M3_H10mm_9774100360 | YES | YES | PART | M3 SMT conductive standoff, 10 mm height; original mounting centers retained. Verify regulator height and mounting interface. | https://www.digikey.com/en/products/result?keywords=9774100360R
J104 | M3 REGULATOR STANDOFF | 9774100360R | Wurth Elektronik | Mounting_Wuerth:Mounting_Wuerth_WA-SMSI-M3_H10mm_9774100360 | YES | YES | PART | M3 SMT conductive standoff, 10 mm height; original mounting centers retained. Verify regulator height and mounting interface. | https://www.digikey.com/en/products/result?keywords=9774100360R
TP101 | SOLDER V7P4 | WIRE_PAD | PCB feature | TestPoint:TestPoint_Pad_D4.0mm | YES | YES | BOARD FEATURE | Solder external regulator output here; strain relief required.
TP102 | SOLDER GND | WIRE_PAD | PCB feature | TestPoint:TestPoint_Pad_D4.0mm | YES | YES | BOARD FEATURE | Solder external regulator output here; strain relief required.
TP103 | SOLDER V5_EXT | WIRE_PAD | PCB feature | TestPoint:TestPoint_Pad_D4.0mm | YES | YES | BOARD FEATURE | Solder external regulator output here; strain relief required.
TP104 | SOLDER GND | WIRE_PAD | PCB feature | TestPoint:TestPoint_Pad_D4.0mm | YES | YES | BOARD FEATURE | Solder external regulator output here; strain relief required.
J105 | UBEC OUT MONITOR | TSW-103-07-G-S | Samtec | Connector_PinHeader_2.54mm:PinHeader_1x03_P2.54mm_Vertical | YES | YES | PART | Monitor only; do not carry servo current through this header. | https://www.digikey.com/en/products/result?keywords=TSW-103-07-G-S
U101 | TLV76750DRVR | TLV76750DRVR | Texas Instruments | Package_SON:WSON-6-1EP_2x2mm_P0.65mm_EP1x1.6mm_ThermalVias | YES | YES | PART | 7.4 V to 5 V logic LDO, 1 A maximum subject to thermal derating. | https://www.digikey.com/en/products/result?keywords=TLV76750DRVR
C101 | 10uF | GRM188R61C106KAALD | Murata | Capacitor_SMD:C_0603_1608Metric | YES | YES | PART |  | https://www.digikey.com/en/products/result?keywords=GRM188R61C106KAALD
C102 | 10uF | GRM188R61C106KAALD | Murata | Capacitor_SMD:C_0603_1608Metric | YES | YES | PART |  | https://www.digikey.com/en/products/result?keywords=GRM188R61C106KAALD
D101 | SS14 | SS14-E3/61T | Vishay | Diode_SMD:D_SMA | YES | YES | PART | Diode OR for logic supplies only, never servo load. | https://www.digikey.com/en/products/result?keywords=SS14-E3/61T
D102 | SS14 | SS14-E3/61T | Vishay | Diode_SMD:D_SMA | YES | YES | PART | Diode OR for logic supplies only, never servo load. | https://www.digikey.com/en/products/result?keywords=SS14-E3/61T
U102 | TLV1117LV33DCYR | TLV1117LV33DCYR | Texas Instruments | Package_TO_SOT_SMD:SOT-223-3_TabPin2 | YES | YES | PART | Ceramic-stable 1117 alternative to AMS1117; 5.5 V maximum input. | https://www.digikey.com/en/products/result?keywords=TLV1117LV33DCYR
C103 | 10uF | GRM188R61C106KAALD | Murata | Capacitor_SMD:C_0603_1608Metric | YES | YES | PART |  | https://www.digikey.com/en/products/result?keywords=GRM188R61C106KAALD
C104 | 10uF | GRM188R61C106KAALD | Murata | Capacitor_SMD:C_0603_1608Metric | YES | YES | PART |  | https://www.digikey.com/en/products/result?keywords=GRM188R61C106KAALD
C105 | 10uF | GRM188R61C106KAALD | Murata | Capacitor_SMD:C_0603_1608Metric | YES | YES | PART |  | https://www.digikey.com/en/products/result?keywords=GRM188R61C106KAALD
F101 | MF-RG900-0 | MF-RG900-0 | Bourns | Fuse:Fuse_Bourns_MF-RG900 | YES | DNP | PART | Populate ONE of F101/F102 only. 9 A hold / 15.3 A trip at 23 C; may interrupt 15 A / 30 s pulse. | https://www.digikey.com/en/products/result?keywords=MF-RG900-0
F102 | MF-RG900-0 | MF-RG900-0 | Bourns | Fuse:Fuse_Bourns_MF-RG900 | DNP | YES | PART | Alternative 5 V servo population; DNP in 7.4 V assembly. | https://www.digikey.com/en/products/result?keywords=MF-RG900-0
J106 | SERVO GND / V+ / PWM | 1711738 | Phoenix Contact | TerminalBlock_Phoenix:TerminalBlock_Phoenix_MKDS-3-3-5.08_1x03_P5.08mm_Horizontal | YES | YES | PART | Current-rated 3-pin screw terminal; 5.08 mm pitch. | https://www.digikey.com/en/products/result?keywords=1711738
R301 | 100 | RC0603FR-07100RL | Yageo | Resistor_SMD:R_0603_1608Metric | YES | YES | PART |  | https://www.digikey.com/en/products/result?keywords=RC0603FR-07100RL
R302 | 100k | RC0603FR-07100KL | Yageo | Resistor_SMD:R_0603_1608Metric | YES | YES | PART |  | https://www.digikey.com/en/products/result?keywords=RC0603FR-07100KL
U201 | ESP32-WROOM-32E-N4 | ESP32-WROOM-32E-N4 | Espressif | RF_Module:ESP32-WROOM-32E | YES | YES | PART |  | https://www.digikey.com/en/products/result?keywords=ESP32-WROOM-32E-N4
C201 | 10uF | GRM188R61C106KAALD | Murata | Capacitor_SMD:C_0603_1608Metric | YES | YES | PART |  | https://www.digikey.com/en/products/result?keywords=GRM188R61C106KAALD
C202 | 100nF | GRM188R71H104KA93D | Murata | Capacitor_SMD:C_0603_1608Metric | YES | YES | PART |  | https://www.digikey.com/en/products/result?keywords=GRM188R71H104KA93D
C203 | 1uF | GRM188R61E105KA12D | Murata | Capacitor_SMD:C_0603_1608Metric | YES | YES | PART |  | https://www.digikey.com/en/products/result?keywords=GRM188R61E105KA12D
R201 | 10k | RC0603FR-0710KL | Yageo | Resistor_SMD:R_0603_1608Metric | YES | YES | PART |  | https://www.digikey.com/en/products/result?keywords=RC0603FR-0710KL
R202 | 10k | RC0603FR-0710KL | Yageo | Resistor_SMD:R_0603_1608Metric | YES | YES | PART |  | https://www.digikey.com/en/products/result?keywords=RC0603FR-0710KL
SW201 | RESET | TL3342F160QG | E-Switch | Button_Switch_SMD:SW_SPST_TL3342 | YES | YES | PART |  | https://www.digikey.com/en/products/result?keywords=TL3342F160QG
SW202 | BOOT | TL3342F160QG | E-Switch | Button_Switch_SMD:SW_SPST_TL3342 | YES | YES | PART |  | https://www.digikey.com/en/products/result?keywords=TL3342F160QG
J201 | UART PROGRAM | TSW-106-07-G-S | Samtec | Connector_PinHeader_2.54mm:PinHeader_1x06_P2.54mm_Vertical | YES | YES | PART | Use 3.3 V UART levels. Pin 2 monitor only; board externally powered. | https://www.digikey.com/en/products/result?keywords=TSW-106-07-G-S
R203 | 100k | RC0603FR-07100KL | Yageo | Resistor_SMD:R_0603_1608Metric | YES | YES | PART |  | https://www.digikey.com/en/products/result?keywords=RC0603FR-07100KL
R204 | 33k | RC0603FR-0733KL | Yageo | Resistor_SMD:R_0603_1608Metric | YES | YES | PART |  | https://www.digikey.com/en/products/result?keywords=RC0603FR-0733KL
C204 | 100nF | GRM188R71H104KA93D | Murata | Capacitor_SMD:C_0603_1608Metric | YES | YES | PART |  | https://www.digikey.com/en/products/result?keywords=GRM188R71H104KA93D
J401 | 20-PIN CONTROL | TSW-110-07-G-D | Samtec | Connector_PinHeader_2.54mm:PinHeader_2x10_P2.54mm_Vertical | YES | YES | PART | All logic signals 3.3 V; do not connect high-voltage flight-controller signals directly. | https://www.digikey.com/en/products/result?keywords=TSW-110-07-G-D
U401 | SN65HVD230DR | SN65HVD230DR | Texas Instruments | Package_SO:SOIC-8_3.9x4.9mm_P1.27mm | YES | YES | PART |  | https://www.digikey.com/en/products/result?keywords=SN65HVD230DR
C401 | 100nF | GRM188R71H104KA93D | Murata | Capacitor_SMD:C_0603_1608Metric | YES | YES | PART |  | https://www.digikey.com/en/products/result?keywords=GRM188R71H104KA93D
R401 | 120 | RC0603FR-07120RL | Yageo | Resistor_SMD:R_0603_1608Metric | DNP | DNP | PART |  | https://www.digikey.com/en/products/result?keywords=RC0603FR-07120RL
R402 | 100k | RC0603FR-07100KL | Yageo | Resistor_SMD:R_0603_1608Metric | YES | YES | PART |  | https://www.digikey.com/en/products/result?keywords=RC0603FR-07100KL
R403 | 100k | RC0603FR-07100KL | Yageo | Resistor_SMD:R_0603_1608Metric | YES | YES | PART |  | https://www.digikey.com/en/products/result?keywords=RC0603FR-07100KL
U501 | AS5600-ASOM | AS5600-ASOM | ams OSRAM | Package_SO:SOIC-8_3.9x4.9mm_P1.27mm | YES | YES | PART | Sensor center retained. Use diametrically magnetized magnet, verify air gap. | https://www.digikey.com/en/products/result?keywords=AS5600-ASOM
C501 | 100nF | GRM188R71H104KA93D | Murata | Capacitor_SMD:C_0603_1608Metric | YES | YES | PART |  | https://www.digikey.com/en/products/result?keywords=GRM188R71H104KA93D
C502 | 1uF | GRM188R61E105KA12D | Murata | Capacitor_SMD:C_0603_1608Metric | YES | YES | PART |  | https://www.digikey.com/en/products/result?keywords=GRM188R61E105KA12D
R501 | 4.7k | RC0603FR-074K7L | Yageo | Resistor_SMD:R_0603_1608Metric | YES | YES | PART |  | https://www.digikey.com/en/products/result?keywords=RC0603FR-074K7L
R502 | 4.7k | RC0603FR-074K7L | Yageo | Resistor_SMD:R_0603_1608Metric | YES | YES | PART |  | https://www.digikey.com/en/products/result?keywords=RC0603FR-074K7L
D601 | TSAL6200 | TSAL6200 | Vishay | LED_THT:LED_D5.0mm_Horizontal_O1.27mm_Z3.0mm | YES | YES | PART | Form leads so optical axes pass through the original mechanical apertures. | https://www.digikey.com/en/products/result?keywords=TSAL6200
R601 | 220 | RC0603FR-07220RL | Yageo | Resistor_SMD:R_0603_1608Metric | YES | YES | PART |  | https://www.digikey.com/en/products/result?keywords=RC0603FR-07220RL
Q601 | 2N7002P,215 | 2N7002P,215 | Nexperia | Package_TO_SOT_SMD:SOT-23 | YES | YES | PART |  | https://www.digikey.com/en/products/result?keywords=2N7002P%2C215
R611 | 100 | RC0603FR-07100RL | Yageo | Resistor_SMD:R_0603_1608Metric | YES | YES | PART |  | https://www.digikey.com/en/products/result?keywords=RC0603FR-07100RL
R621 | 100k | RC0603FR-07100KL | Yageo | Resistor_SMD:R_0603_1608Metric | YES | YES | PART |  | https://www.digikey.com/en/products/result?keywords=RC0603FR-07100KL
D602 | TSAL6200 | TSAL6200 | Vishay | LED_THT:LED_D5.0mm_Horizontal_O1.27mm_Z3.0mm | YES | YES | PART | Form leads so optical axes pass through the original mechanical apertures. | https://www.digikey.com/en/products/result?keywords=TSAL6200
R602 | 220 | RC0603FR-07220RL | Yageo | Resistor_SMD:R_0603_1608Metric | YES | YES | PART |  | https://www.digikey.com/en/products/result?keywords=RC0603FR-07220RL
Q602 | 2N7002P,215 | 2N7002P,215 | Nexperia | Package_TO_SOT_SMD:SOT-23 | YES | YES | PART |  | https://www.digikey.com/en/products/result?keywords=2N7002P%2C215
R612 | 100 | RC0603FR-07100RL | Yageo | Resistor_SMD:R_0603_1608Metric | YES | YES | PART |  | https://www.digikey.com/en/products/result?keywords=RC0603FR-07100RL
R622 | 100k | RC0603FR-07100KL | Yageo | Resistor_SMD:R_0603_1608Metric | YES | YES | PART |  | https://www.digikey.com/en/products/result?keywords=RC0603FR-07100KL
Q603 | TEFT4300 | TEFT4300 | Vishay | LED_THT:LED_D3.0mm_Horizontal_O1.27mm_Z2.0mm | YES | YES | PART | Pad 1 collector / pad 2 emitter. Confirm lead orientation during formed-lead assembly. | https://www.digikey.com/en/products/result?keywords=TEFT4300
R603 | 10k | RC0603FR-0710KL | Yageo | Resistor_SMD:R_0603_1608Metric | YES | YES | PART |  | https://www.digikey.com/en/products/result?keywords=RC0603FR-0710KL
C601 | 100nF | GRM188R71H104KA93D | Murata | Capacitor_SMD:C_0603_1608Metric | YES | YES | PART |  | https://www.digikey.com/en/products/result?keywords=GRM188R71H104KA93D
U601 | TSSP4038 | TSSP4038 | Vishay | OptoDevice:Vishay_MOLD-3Pin | YES | YES | PART |  | https://www.digikey.com/en/products/result?keywords=TSSP4038
R604 | 100 | RC0603FR-07100RL | Yageo | Resistor_SMD:R_0603_1608Metric | YES | YES | PART |  | https://www.digikey.com/en/products/result?keywords=RC0603FR-07100RL
C602 | 100nF | GRM188R71H104KA93D | Murata | Capacitor_SMD:C_0603_1608Metric | YES | YES | PART |  | https://www.digikey.com/en/products/result?keywords=GRM188R71H104KA93D
C603 | 1uF | GRM188R61E105KA12D | Murata | Capacitor_SMD:C_0603_1608Metric | YES | YES | PART |  | https://www.digikey.com/en/products/result?keywords=GRM188R61E105KA12D
H101 | M3 MOUNT | M3_HARDWARE | Mechanical | MountingHole:MountingHole_3.2mm_M3 | YES | YES | BOARD FEATURE | Original hole center and 3.2 mm drill retained.
H102 | M3 MOUNT | M3_HARDWARE | Mechanical | MountingHole:MountingHole_3.2mm_M3 | YES | YES | BOARD FEATURE | Original hole center and 3.2 mm drill retained.
H103 | M3 MOUNT | M3_HARDWARE | Mechanical | MountingHole:MountingHole_3.2mm_M3 | YES | YES | BOARD FEATURE | Original hole center and 3.2 mm drill retained.
H104 | M3 MOUNT | M3_HARDWARE | Mechanical | MountingHole:MountingHole_3.2mm_M3 | YES | YES | BOARD FEATURE | Original hole center and 3.2 mm drill retained.
H105 | M3 MOUNT | M3_HARDWARE | Mechanical | MountingHole:MountingHole_3.2mm_M3 | YES | YES | BOARD FEATURE | Original hole center and 3.2 mm drill retained.
H106 | M3 MOUNT | M3_HARDWARE | Mechanical | MountingHole:MountingHole_3.2mm_M3 | YES | YES | BOARD FEATURE | Original hole center and 3.2 mm drill retained.

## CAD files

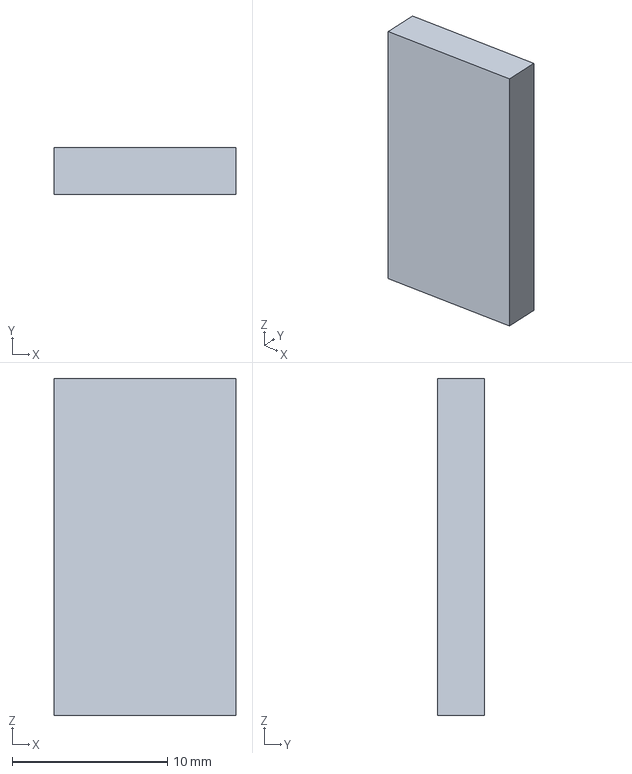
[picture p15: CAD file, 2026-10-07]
GPT6 New/3D/Models/MF-RG900-envelope.step
11.7 x 3.00 x 21.7 mm

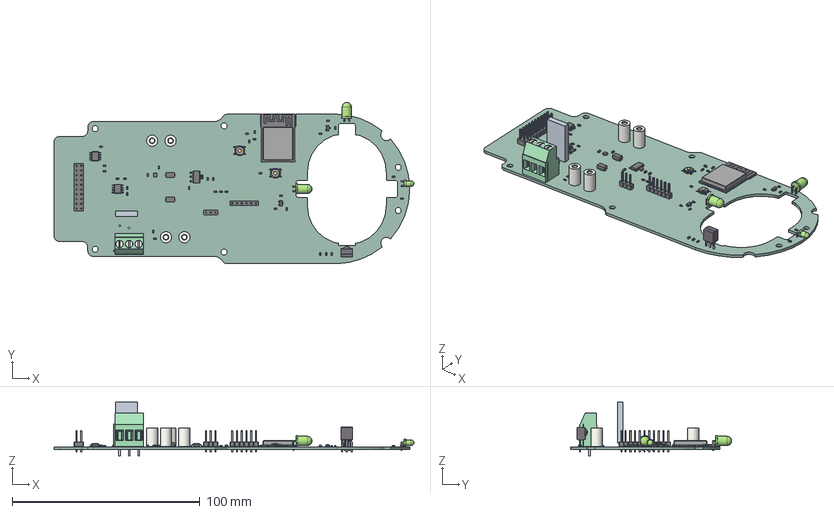
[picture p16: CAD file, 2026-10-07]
GPT6 New/3D/Rdrop-GPT6.step
191.8 x 86.0 x 28.7 mm
ESP32-WROOM-32E
R_0603_1608Metric x 18
C_0603_1608Metric x 15
PinHeader_1x03_P254mm_Vertical
SOT-23 x 2
PinHeader_2x10_P254mm_Vertical
LED_D5.0mm_Horizontal_O1.27mm_Z3.0mm x 2
D_SMA x 2
SW_SPST_TL3342 x 2
MF-RG900 envelope
Mounting_Wuerth_WA-SMSI-M3_H10mm_9774100360 x 4
SOIC-8_3.9x4.9mm_P1.27mm x 2
Vishay_MOLD-3pin
WSON_6_1EP_2x2mm_P065mm_EP1x16mm
SOT-223
PinHeader_1x06_P254mm_Vertical
LED_D3.0mm_Horizontal_O1.27mm_Z2.0mm
TerminalBlock_Phoenix_MKDS-3-3-5.08_1x03_P5.08mm_Horizontal
Rdrop-GPT6_PCB

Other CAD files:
GPT6 New/3D/Rdrop-GPT6-B.step

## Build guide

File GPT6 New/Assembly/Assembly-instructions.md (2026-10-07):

# Assembly

Variant A: fit F101; leave F102 empty; servo receives the external 7.4 V rail.
Variant B: fit F102; leave F101 empty; servo receives the external 5 V rail.
Never populate both fuses: doing so joins the two external supplies through the fuses.

R401 is optional CAN bus termination and is DNP in both supplied BOMs.
The board features (four wire pads and six M3 holes) are not purchased components.
Solder external supply wires to TP101/TP102 for 7.4 V, or TP103/TP104 for 5 V. Use suitably rated wire and strain relief. Standoffs are retained at the original centers; do not assume their unspecified electrical-current rating supports 15 A.
J106 screw terminal pins 1/2/3: GND / servo positive / PWM. Verify polarity before connecting a servo.
J105 pins 1/2/3: GND / 7.4 V UBEC monitoring / unused. It is a low-current monitoring header and cannot carry servo current.
J201 pins 1..6: GND, 3.3 V monitor, UART TX, UART RX, EN, BOOT. Use a 3.3 V UART adapter and a common ground.

CPL positions are KiCad absolute coordinates in millimetres; Y is negative upward, angles are native KiCad angles, top side only. SMD-only files are for automated placement; manual THT files include terminals, headers, radial fuses and optical parts. Check rotations against pin 1 and the assembly drawing before production. Vendor-specific rotation corrections have not been certified.

Form the horizontal optical-device leads to the original optical axes and verify their assembled height. Generic standard KiCad LED models show shape rather than authentic IR component color. The fuse model is a conservative rectangular body envelope, not detailed vendor CAD; reserve 23.7 mm above the PCB for it.
The four standard footprint-instance silkscreens near overhanging parts were tailored to the actual outline. All pad geometry remains equal to the standard library footprints. The four library comparison warnings document these graphical changes.

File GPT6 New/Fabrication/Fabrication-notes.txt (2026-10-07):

RDROP GPT6 REV A — PROTOTYPE FABRICATION NOTES
2 copper layers; nominal finished thickness 1.60 mm; FR-4; ENIG; green soldermask; white silkscreen.
Finished copper: 70 um (2 oz) on BOTH faces. Do not substitute 1 oz.
Specify at least 25 um finished plated-through-hole copper wall thickness, including power-transition via arrays.
Minimum copper width/spacing 0.20 mm; copper-to-routed-edge 0.30 mm.
Smallest plated hole: 0.20 mm (standard WSON / ESP32 thermal-pad holes). Route vias 0.30/0.35 mm.
Minimum via annular ring 0.15 mm for newly placed 0.60/0.30 mm and 0.70/0.35 mm vias.
Use separate PTH and NPTH Excellon files. Preserve the supplied outline and internal cutout exactly.
Tent ordinary vias. Match component-pad mask/paste apertures to Gerbers; inspect via-in-pad paste process.
The ESP32 and WSON standard footprints contain thermal plated holes; assembler must assess solder wicking.
Conductive regulator standoffs use standard Wurth copper lobes adjacent to NPTH; intentional same-footprint hole-clearance exception is included in KiCad rules.
Gerbers and drills use absolute board coordinates, millimetres. No panelization or V scoring supplied.
Assemble VARIANT A (7.4 V) unless the customer explicitly orders VARIANT B (5 V).
Fit exactly one of F101/F102. R401 120-ohm CAN terminator is DNP unless this node is an endpoint.
Inspect all connector pin 1 marks and semiconductor polarity against schematic and assembly drawing.
Prototype electrical, thermal, optical and installed-mechanical qualification is required before flight.

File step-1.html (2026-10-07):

RDROP / GPT6 REVIEW

Step 01 / Functional review

# Find the risks. Decide what to change.

GPT6 reviewed the existing Rdrop design. The developer verified recommendations and implemented selected circuit corrections.

12Recommendations

5Updated per developer notes

1Additional path check

6Retained / acknowledged / deferred

## What the analysis delivered.

A functional review covering power selection, current measurement, encoder wiring, IR circuits, CAN, programming and protection. It also estimated electronics current and defined release tests.

The 23 September review did not implement electrical changes. Later developer updates are recorded separately; do not treat its findings as the state of the final updated baseline.

## Recommendations and developer decisions.

Find a topic or action

Topic / generated finding | Developer disposition
UBEC input limit 14S maximum conflicts with an 18S installation. | Acknowledged Use this UBEC only on 14S drones.
Servo source selection Both fitted fuses can join the 5 V and 7.4 V rails. | Existing practice retained Populate only one fuse for the chosen regulator; developer also notes existing Schottky protection.
Servo current sensing Original 0.1 Ω shunt dissipates 4.9 W at 7 A; measurement scaling saturates. | Updated Shunt and resistor values updated.
Complete high-current path Check fuses, connectors, standoffs and copper bottlenecks. | Checked by developer Fuse suitability, J1/J2 planes, 30 A standoff rating and JAE suitability double-checked.
AS5600 supply / I²C Correct supply connections and add SDA/SCL pull-ups. | Updated 5 V connections corrected and I²C pull-ups added.
IR emitter drive Series visible/IR LEDs limit optical current. | Updated Emitter/indicator circuit changed from series to parallel.
TSSP4038 output load Output should not directly carry the heavy indicator/inverter load. | Updated LED moved near Q601.
Analog TEFT4300 node Indicator loading affects the analog sensor node. | Retained after testing Developer reports extensive circuit review and successful testing of the current configuration.
CAN termination Fit termination only as required by bus topology. | Updated R702 removed and marked DNP; option retained for an un-terminated peer.
Regulator stability / heat Validate headroom, effective capacitance and enclosed temperature. | Deferred Thermal verification deferred for time; regulator choice had senior engineer approval.
USB power / signal levels Review programming backfeed and external logic voltage. | Retained after prior review Developer notes this passed the previous review.
Raw battery protection Confirm protection and insulation across the system. | Retained after prior review Developer notes prior review, expected-current planes and fuses elsewhere in the power path.

Important distinction: source selection

The developer retains the one-fuse assembly rule. The original review notes that logic-branch Schottky diodes do not isolate the bypass between servo rails if both fuses are fitted.

Recorded checks and current estimates

Historical review: 81 ERC findings; 75 PCB DRC findings including 10 starved-thermal errors; 0 unconnected items; 46 separate parity findings related to datasheet fields. Metadata findings are not 46 proven connectivity faults.

Illustrative electronics totals excluding servo: approximately 0.10 A original / 0.14 A corrected with RF off; 0.29 A / 0.33 A with TX activity. Capacity allowances: 0.65 A / 0.75 A. These are planning scenarios, not measurements.

Developer perspective

## Your review, distilled.

Paraphrased from your notes; separate from the generated analysis.

Changes implemented

Current-sense values, AS5600 wiring and pull-ups, IR circuits, receiver indicator placement and optional CAN termination.

Reviewed and retained

TEFT4300 circuit retained after reported testing; USB and battery-protection approach retained after previous reviews.

Known boundaries

The named UBEC is reserved for 14S drones. Only one servo fuse is fitted.

Validation deferred

Regulator thermal qualification was deferred because of time constraints.

Overall assessment

The review identified useful functional issues; the developer applied changes selectively after verification.

## Visual context for the review.

These images show the later updated baseline and the supplied reference views. The exact historical annotated review project is not present in this workspace.

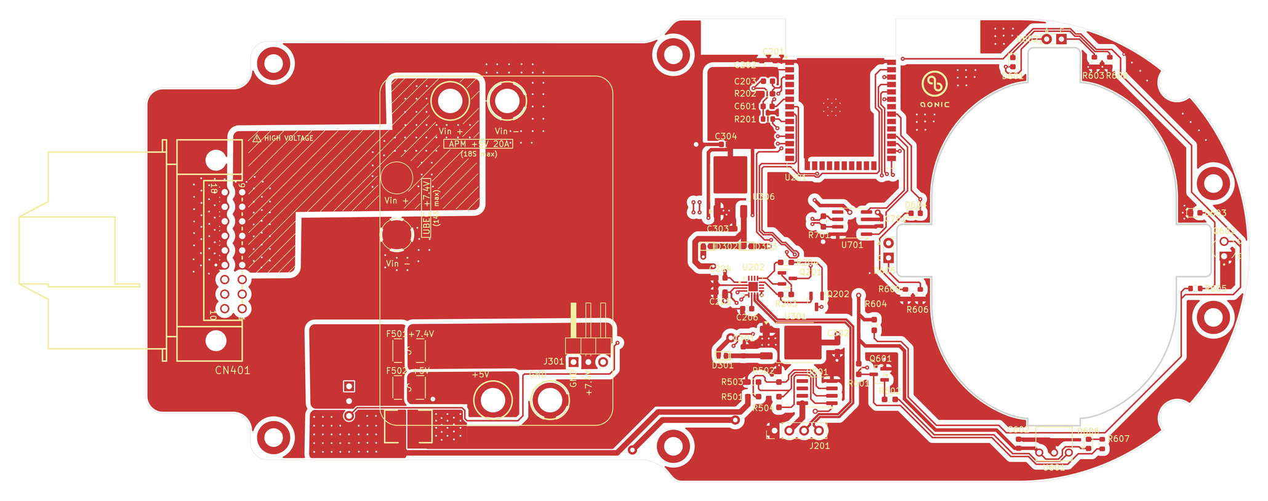
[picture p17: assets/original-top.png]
Updated baseline / top copper


Updated baseline / top copper

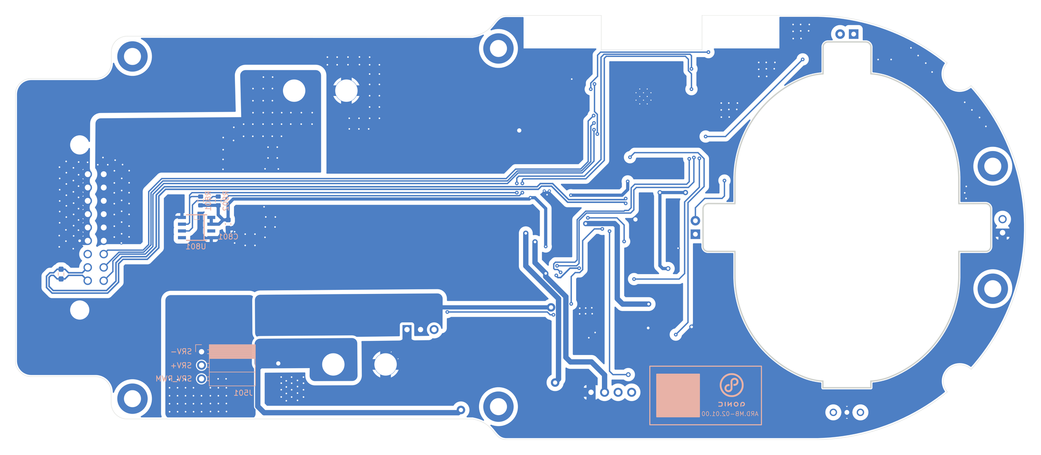
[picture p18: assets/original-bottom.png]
Updated baseline / bottom copper, viewed from above


Updated baseline / bottom copper, viewed from above

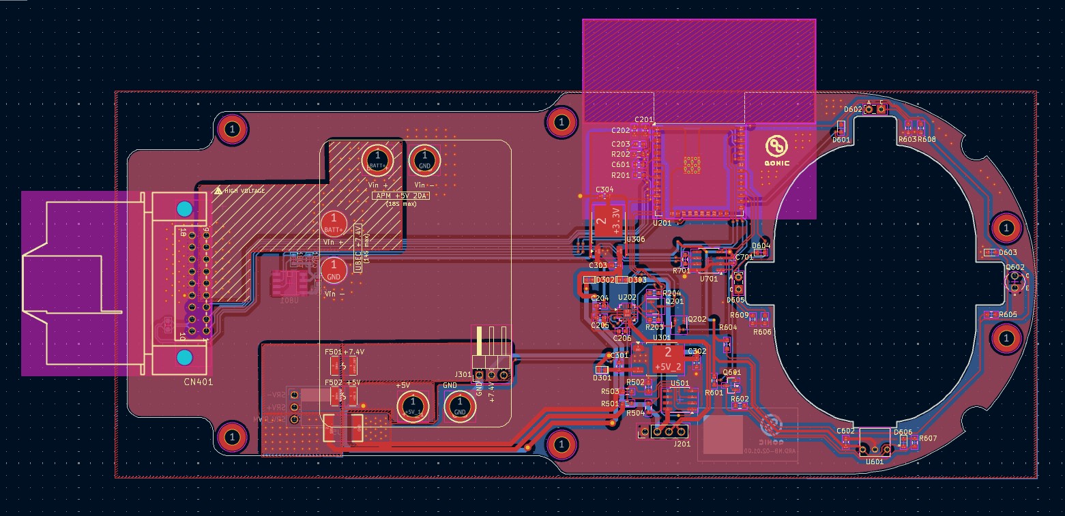
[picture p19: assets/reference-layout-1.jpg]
Supplied reference / PCB layout view 1


Supplied reference / PCB layout view 1

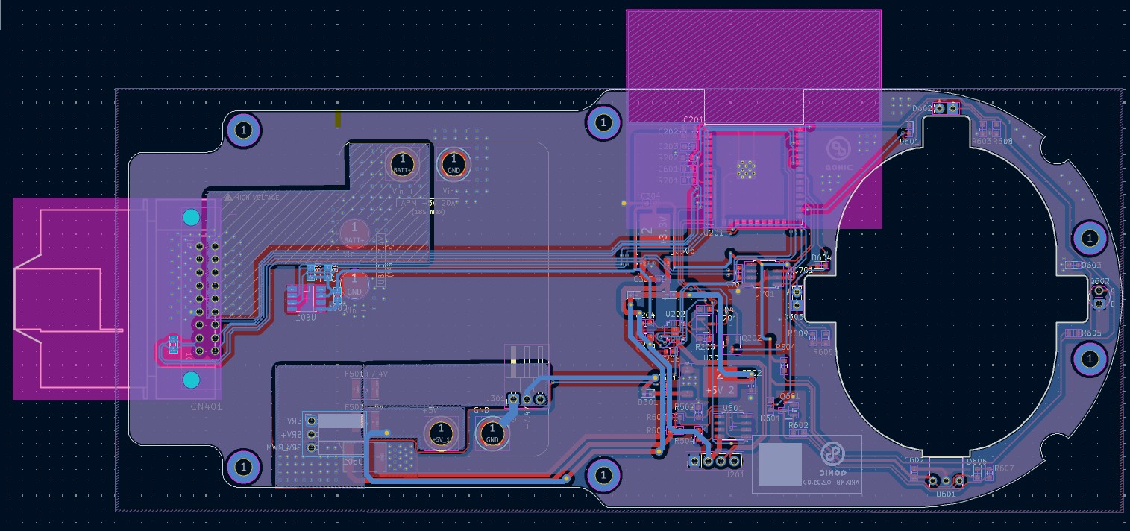
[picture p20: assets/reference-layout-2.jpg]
Supplied reference / PCB layout view 2


Supplied reference / PCB layout view 2

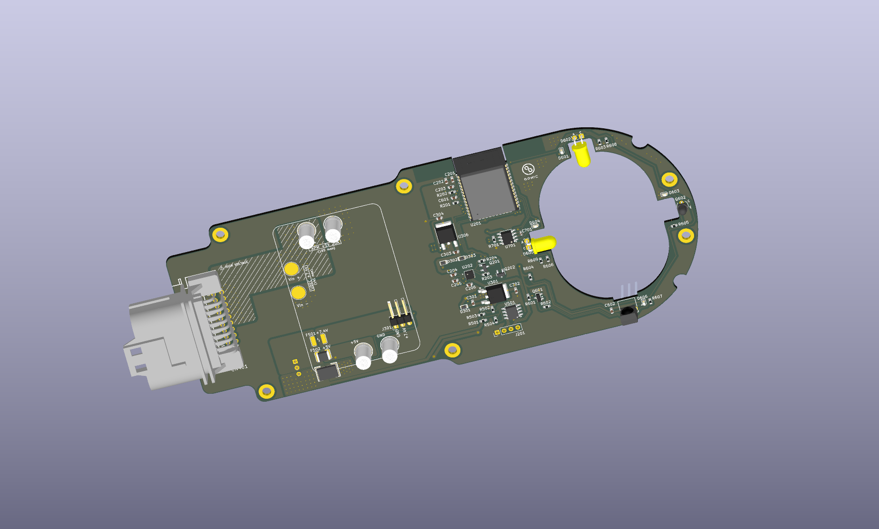
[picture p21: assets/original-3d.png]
Updated baseline / assembled 3D


Updated baseline / assembled 3D

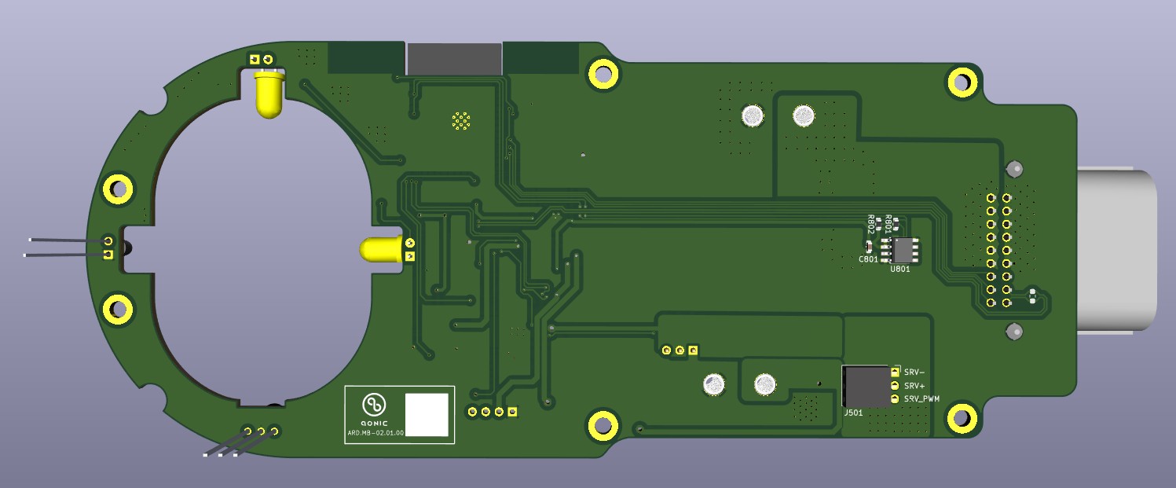
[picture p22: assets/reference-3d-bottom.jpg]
Supplied reference / underside 3D


Supplied reference / underside 3D

## Developer’s circuit examples.

Source screenshots accompanying the Step 1 dispositions.

Developer notes / circuit example

Developer notes / circuit example

Developer notes / circuit example

Developer notes / circuit example

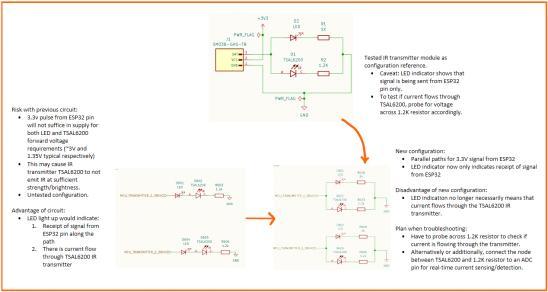
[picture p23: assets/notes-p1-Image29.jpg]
Developer notes / circuit example


Developer notes / circuit example

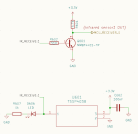
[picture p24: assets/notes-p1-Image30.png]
Developer notes / circuit example


Developer notes / circuit example

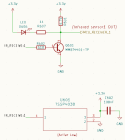
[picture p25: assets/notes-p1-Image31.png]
Developer notes / circuit example


Developer notes / circuit example

Developer notes / circuit example

Developer notes / circuit example

## Download Step 1 evidence.

Includes the source review, developer notes and clearly labelled visual context. This is a review package, not a fabrication release.

Download ZIP · 1.5 MB

← OverviewNext: conservative refinement →

Rdrop Astra · Consolidated evaluation · 7 October 2026
Developer comments are concise paraphrases of ChatGPT6 Analysis.pdf. Generated checks describe their recorded revisions; they do not establish flight or thermal qualification.
Developer source notes · Step 1 source review

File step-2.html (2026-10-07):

RDROP / GPT6 REVIEW

Step 02 / Conservative refinement

# Improve the copper. Keep the design intact.

GPT6 edited the updated board’s ground fill, stitching and selected power traces while retaining the schematic, outline, components and placement.

78 → 78PCB footprints

+40Ground stitching vias

+12.0%Top ground area

+8.4%Bottom ground area

## Accepted changes.

Change | Before → after
Main ground clearance | 0.8 → 0.3 mm
Ground vias | 299 → 339 total board vias
+5V_1 trace segments | 1.0 → 1.5 mm on 12 segments / 77.04 mm
+5V_2 trace segments | 1.0 → 1.5 mm on 6 segments / 27.60 mm
+UBEC_OUT segments | 0.8 → 1.2 mm on 4 segments / 9.22 mm
J301 ground connection | Thermal → solid zone connection

Seven proposed width increases were rejected by DRC and restored. Wider segments do not establish a uniformly wider current path.

## Execution and verification.

Native KiCad files were edited using KiCad 9’s board engine and opened for visual review. Placement, pad geometry, net assignments, outline and all schematic files were verified unchanged.

Both recorded versions: 0 DRC errors, 80 existing warnings, 0 unconnected items and 0 parity conflicts. No bench test establishes 15 A capability or the requested temperature rise.

Developer perspective

## Your review, distilled.

Paraphrased from your notes; separate from the generated analysis.

Ground clearance

Good reduction of excessive clearance: more return copper and fewer isolated thermal-spoke conditions.

Stitching placement

Useful stitching of wide areas, but placement feels random and intrudes into the serial barcode region.

Power trace widths

Good initiative, but changes occur mid-trace, are abrupt and lack tapering; narrow sections remain. Original 1 mm was considered sufficient for the relatively low 5 V load.

Layout scope

No component-placement or overall routing optimization was attempted.

Overall assessment

Minimal and conservative. Stronger execution would use consistent widths and more intentional via placement; the supplied verification records are useful.

## Top copper.

Side by sideOriginal onlyRefined only

Updated original / top copper

Updated original / top copper

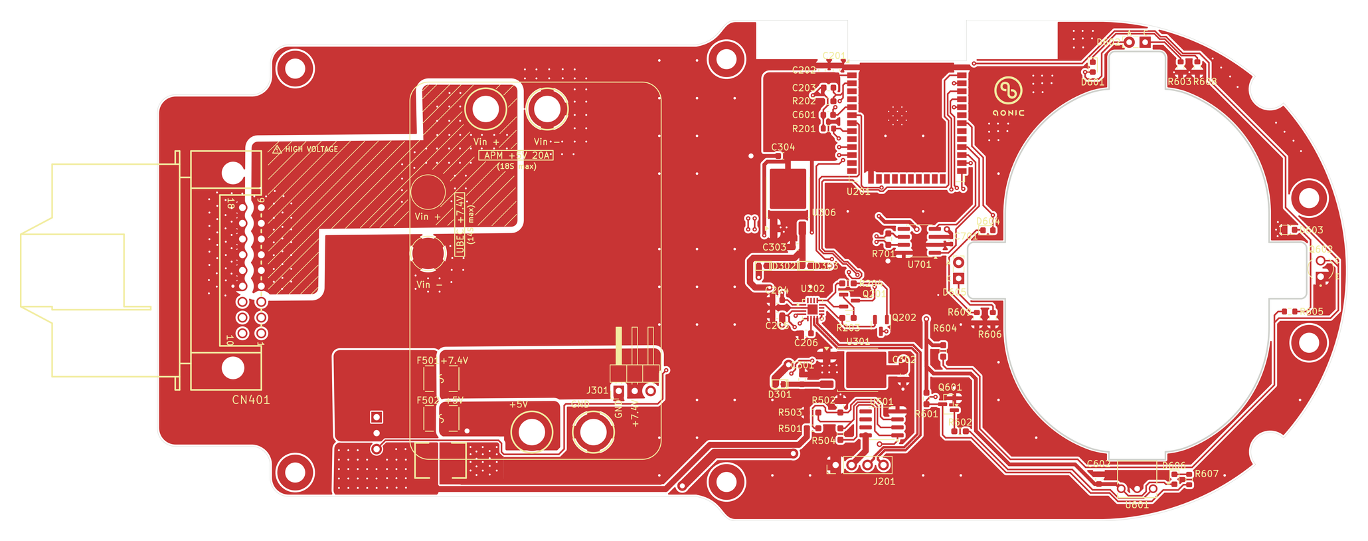
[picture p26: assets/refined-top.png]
Refined / top copper


Refined / top copper

## Bottom copper.

Side by sideOriginal onlyRefined only

Updated original / bottom copper

Updated original / bottom copper

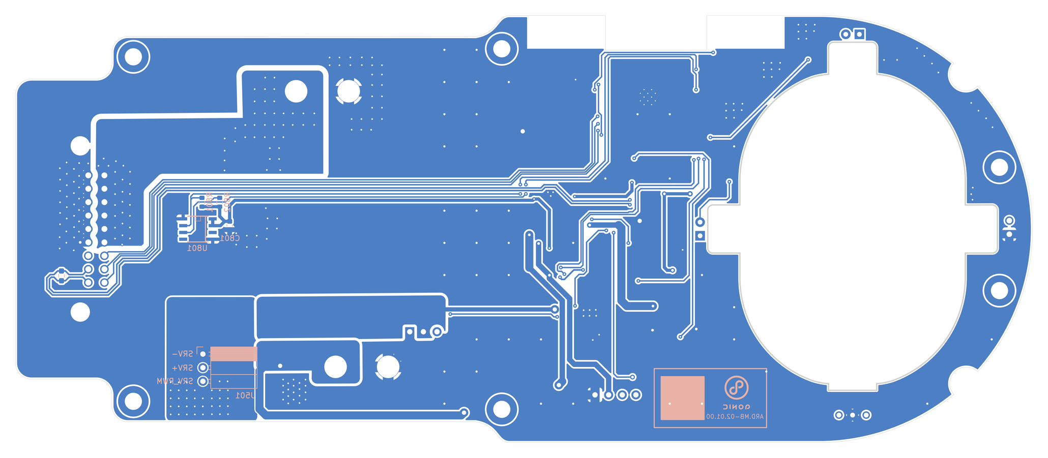
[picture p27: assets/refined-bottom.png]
Refined / bottom copper


Refined / bottom copper

## Assembled 3D.

Side by sideOriginal onlyRefined only

Updated original / 3D view

Updated original / 3D view

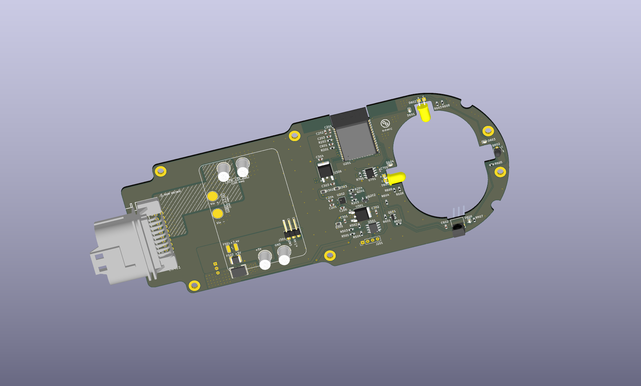
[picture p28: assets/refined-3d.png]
Refined / unchanged component placement


Refined / unchanged component placement

Step 2 pairs use the same view, scale and layers. Bottom views are both shown from above without mirroring.

## Developer’s marked examples.

Original small screenshots from the developer PDF; use the full-size board images above for detailed inspection.

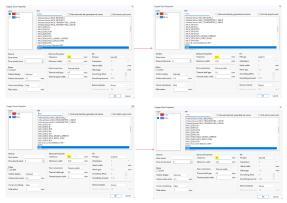
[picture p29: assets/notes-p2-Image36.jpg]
Developer notes / embedded example from page 2


Developer notes / embedded example from page 2

Developer notes / embedded example from page 2

Developer notes / embedded example from page 2

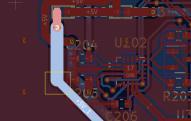
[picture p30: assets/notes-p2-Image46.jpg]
Developer notes / embedded example from page 2


Developer notes / embedded example from page 2

## Download Step 2 comparison.

Includes both native projects, comparison images, change records, PDF reports and developer notes. Inherited custom libraries may require the original library environment.

Download ZIP · 7.9 MB

Open the original comparison website ↗Full refinement reportDeveloper notes PDF

← Functional reviewNext: complete redesign →

Rdrop Astra · Consolidated evaluation · 7 October 2026
Developer comments are concise paraphrases of ChatGPT6 Analysis.pdf. Generated checks describe their recorded revisions; they do not establish flight or thermal qualification.
Developer source notes · Step 1 source review

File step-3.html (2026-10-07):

RDROP / GPT6 REVIEW

Step 03 / Complete redesign

# A complete new board. A foundation to refine.

GPT6 generated a replacement ESP32 design with a new circuit, routed PCB, 3D models and manufacturing exports within the inherited outline and cutout.

7Schematic sheets

69PCB footprints

2 ozCopper on both layers

0ERC / DRC errors

## What was generated.

- ESP32-WROOM-32E, AS5600 and the two required IR sensor pairs.
- Separate emitter drivers, CAN interface, 20-pin interface and UART programming header.
- Logic LDOs: TLV76750 and TLV1117LV33 ceramic-compatible alternatives.
- Current-rated 3-pin servo terminal and one-of-two MF-RG900 fuse options.
- Regulator standoffs and solder pads retained; battery conversion remains external.
- Gerbers, Excellon drills, variant BOMs, placement files, STEP/GLB models and connection tables.

Recorded verification: 0 ERC violations; 0 DRC errors; 0 unrouted items; 0 parity conflicts. Four footprint-library comparison warnings document intentional graphics changes. These checks do not validate circuit function or thermal performance.

Current, fuse and thermal boundaries

The later brief specifies 5–7 A normal servo current and 15 A for 30 seconds. The developer chose approximately 15 A trip over guaranteed pulse endurance: MF-RG900 can interrupt that pulse. The redesigned board uses 2 oz copper; it is not an equivalent 1 oz comparison.

Named 3–14S UBEC is appropriate only within its input rating. The Step 1 developer notes report a 20 A APM rating, while the redesign report requests exact model and pulse/thermal evidence. Preserve that distinction; source ratings do not qualify the complete PCB path.

Developer perspective

## Your review, distilled.

Paraphrased from your notes; separate from the generated analysis.

Circuit validation

Needs extensive circuit, inter-circuit and placement validation. Individual IR drivers are a positive addition.

Routing quality

Some straight horizontal routes are good; other routes are awkward and appear influenced by walkaround behavior.

Power distribution

Developer prefers dedicated power planes over very large 4.5 mm power traces, to improve efficiency and reduce loop inductance and noise.

Product integration

Connector placement needs clearer user constraints. A freely chosen outline could permit a more efficient layout.

Schematic readability

The generated schematic requires extensive zooming to read comfortably.

Workflow value

Fabrication exports and the connection list are useful automation outputs. Git integration is a future opportunity.

Component count

69 versus 78 footprints is fewer, but footprint count alone does not establish BOM cost savings.

Overall assessment

Passable and promising as a starting point; thoughtful layout refinement and validation are still needed.

## PCB layout comparison.

The inherited geometry is retained; the circuitry and placement are newly generated. The original and redesign exports have different presentation layers and scales.

Updated original / top copper

Updated original / top copper

New design / top copper and outline

New design / top copper and outline

New design / top assembled view

New design / top assembled view

New design / bottom assembled view

New design / bottom assembled view

## 3D and assembly comparison.

Updated original / assembled 3D

Updated original / assembled 3D

New design / assembled 3D, variant A

New design / assembled 3D, variant A

Supplied original reference / underside

Supplied original reference / underside

New design / fabrication-layer assembly view

New design / fabrication-layer assembly view

Standard library component models illustrate placement. The resettable fuse uses a conservative body envelope, not detailed manufacturer CAD.

## Developer’s annotated examples.

Embedded screenshots from the source notes; low-resolution evidence, not substitutes for native CAD.

Developer notes / redesign example

Developer notes / redesign example

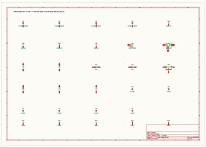
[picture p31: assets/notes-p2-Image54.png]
Developer notes / redesign example


Developer notes / redesign example

Developer notes / redesign example

Developer notes / redesign example

## Download Step 3 native project.

Complete redesign package: schematic, PCB, local 3D models, BOM/CPL variants, manufacturing exports, report and verification records. Prototype qualification remains required.

Download ZIP · 4.6 MB

Gerbers + drills ZIP

Open the original redesign website ↗Developer notes PDF

← Conservative refinementBack to overview →

Rdrop Astra · Consolidated evaluation · 7 October 2026
Developer comments are concise paraphrases of ChatGPT6 Analysis.pdf. Generated checks describe their recorded revisions; they do not establish flight or thermal qualification.
Developer source notes · Step 1 source review

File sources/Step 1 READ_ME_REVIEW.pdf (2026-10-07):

# Rdrop main-board functional review

Reviewed 23 September 2026. Disposition: do not release the present design for fabrication as a verified 15 A continuous board. Several circuit corrections are needed independently of copper width. This is a design review, not a tested prototype qualification.
The adjacent PCB | Design | - | Review project contains review
annotations only. Its electrical connections and copper are unchanged. The annotations identify required changes; they are not evidence that those changes have been implemented. Original source, manufacturing and mechanical files are preserved. See verification.json for the preservation and copy checks.

## Scope and evidence

Reviewed the current eight-sheet schematic, exported connectivity, PCB pads/tracks/zones, BOM, reference drawings, and the available mechanical STEP file headers/assembly context. Ran KiCad schematic ERC and PCB DRC, including schematic parity. The evidence folder contains the netlist, check reports and extracted PCB geometry. The existing STEP files are accessible locally, including Mechanical/ ard.mb-02.01.00.step and the _withPM.step version; neither has been changed. A native CAD interference/clearance analysis has not been performed.
Design assumptions supplied by the owner: two layers, 1 oz copper, JLCPCB manufacture; 15 A continuous capacity with at most 15–20°C copper temperature rise; 18S / 78 V input; custom APM rated 5 V / 20 A continuously; Tiankong RC H20/35 servo with approximately 7 A peaks at 7.4 V; Hobbywing UBEC-10A-HV(3-14S)-V1. The PCB file specifies

1.6 mm thickness. APM continuous rating is accepted as ownersupplied, not independently certified here.
Missing evidence: Butiks (1).DXF, full casing/gear assembly and tolerances, exact servo manufacturer specification, APM schematic/ protection/efficiency and test record, firmware, exact ratings for several sourced parts. These prevent a complete mechanical, firmware and system-level sign-off. Findings below distinguish confirmed connectivity faults from parts requiring qualification.

## What the power circuit actually does

Path | Connectivity in the current source
Drone battery | CN1 pins 4–9 → BATT+ → U302 conductive standoff → APM input; CN1 pins 13–18 and U303 are ground
APM output | U304 supplies +5V_1; U305 is its ground. +5V_1 → F2 → SRV+; separately +5V_1 → D302 → +5V logic rail
UBEC output | J1 pin 2 → +UBEC_OUT → F1 → SRV+; separately +UBEC_OUT → D301 → U301 LM1084-5.0 → D303 → +5V logic rail
Logic | +5V → U306 BL8072-3.3 → ESP32/CAN/IR/encoder. CH343 and LM358 also take power from +5V
Servo return | J2 pin 1 → SRV− → 0.501, a 0.1 Ω shunt → board ground

The LM1084 does not carry servo current in this schematic. It regulates the UBEC-fed logic branch. The APM bypasses it as intended. The logic net called +5V is lower than 5 V by D302 or D303's forward drop. U302–U305 are conductive mechanical standoffs, not semiconductor devices.

## Corrections required for functionality

### 1. Replace the specified UBEC for an 18S / 78 V

installation

Confirmed mismatch. Hobbywing specifies the exact 10A HV model for 3–14S and 10 A continuous; 25 A is instantaneous. It therefore fails both the stated input requirement and the 15 A continuous output requirement. Select a converter qualified for the actual maximum battery voltage plus measured transients, 7.4 V output, and at least the required continuous load at enclosure temperature. A nominal 80 V limit leaves only 2 V against the stated 78 V maximum; it needs explicit transient assessment. A suitably designed 100 V-class input stage is a more useful starting specification, not automatic proof of suitability. Hobbywing specification
The APM's owner-confirmed 20 A continuous rating makes the 5 V route the more direct starting point, provided the servo's permitted voltage and delivered torque/speed at 5 V are established. A module's output rating does not qualify the PCB, standoffs, fuse or servo connector.

### 2. Make the 5 V / 7.4 V selection mutually exclusive

Confirmed connectivity hazard if both source paths are enabled. F1 and F2 join at SRV+. Fuses conduct in both directions; they do not isolate supplies. With both fitted and both sources present, 7.4 V can feed the APM's 5 V output through F2 and then the logic rail through D302. D302/D303 do not isolate this bypass route. An unpowered converter can also be backfed.
For a fixed assembly variant, populate only the selected servo path, explicitly mark the other DNP in the schematic, PCB and assembly BOM, and label the permitted configuration. For field selection, use a break-before-make selector or reverse-current-blocking power switch arrangement rated for the full continuous current, inrush and voltage. Avoid ordinary small signal jumpers. If both converters may remain connected for logic power, confirm each permits its resulting unpowered/ output conditions.
The existing fabrication BOM lists F2 only, but the PCB does not mark

F1 DNP. This may represent an intended APM-only build; resolve the inconsistency rather than assuming both fuses are physically assembled. Updating a BOM alone is inadequate protection against an incorrectly configured assembly.

### 3. Replace the servo shunt and redesign the current

measurement

Confirmed electrical failure at the target current. Reference 0.501, RA2512F3R100G, is 0.1 Ω. Its listed 3 W power rating still requires primary manufacturer confirmation, but the calculated dissipation already demonstrates the problem:

Servo current | Shunt voltage loss | Shunt heat
7 A | 0.70 V | 4.90 W
15 A | 1.50 V | 22.50 W

With a nominal 3 W rating, √(3/0.1) = 5.48 A is the theoretical underated DC limit, not a safe design current. At 7 A the nominal 7.4 V servo supply becomes approximately 6.7 V before other wiring losses. The raised servo ground also reduces a 3.3 V PWM high to approximately 2.6 V relative to the servo at 7 A, or 1.8 V at 15 A.
R501/R502 attenuate the shunt signal by 10/11; R503/R504 set LM358 gain to 11. The net gain is 10, giving an ideal 1 V/A. Thus 7 A demands 7 V output from an amplifier powered by less than 5 V, and the signal can exceed the ESP32 ADC range well before the requested full scale. Saturation is not overvoltage protection.
Recommended implementation: a 2 mΩ shunt, at least 3 W with its specified PCB thermal conditions, four-terminal/Kelvin sensing, placed in the low-voltage servo positive rail, and INA180A2 gain 50 supplied from 3.3 V. This yields 0.1 V/A: 0.7 V at 7 A, 1.5 V at 15 A and 2.0 V at 20 A. Shunt loss becomes 14 mV / 0.098 W at 7 A and 30 mV / 0.45 W at 15 A. Servo ground can then connect directly to common ground. Include 100 nF bypass, an ADC filter, input transient assessment and calibration. This amplifier belongs on the 5/7.4 V rail, never the 78 V input; its common-mode limit is 26 V. It is unidirectional: use a bidirectional alternative if regenerative current must be measured. Verify exact A/B package pinout. TI INA180 datasheet
The INA180's input offset makes very small currents relatively inaccurate with a 2 mΩ shunt; the proposed scaling prioritizes jam/ overload measurement. Set software thresholds from calibrated current and time, not one instantaneous ADC sample. If retaining U501 for another purpose, terminate its unused B amplifier in a valid closed-loop configuration and add local decoupling; its second unit is presently absent from the schematic.

### 4. Qualify the entire 15 A path, including fuses and

connectors

Unqualified and likely underspecified components. F1/F2 TLC-MSML750/12 have not been supported by a retrieved manufacturer datasheet. The apparent 7.5 A hold / 15 A trip designation must be verified; a 15 A trip rating is not a 15 A continuous rating. Obtain the hold-current derating, resistance, trip curves, voltage and interrupt/fault rating. Replace as necessary with protection coordinated to the cable, connector, copper and source. Do not simply install a larger fuse without upgrading the protected path. Any 12 V-rated protection belongs only on a low-voltage branch, not raw battery.
J1 and J2 use a single 2.54 mm power contact and a single return contact. No evidence establishes 15 A continuous capability for these exact parts. Replace the high-current connections with documented, suitably derated locking power connectors or strain-relieved soldered cable pads, including the servo pigtail. A 20 A-or-higher connector rating can provide margin only if its ambient, wire size and mating conditions match this installation.
Qualify the U304/U305 conductive standoffs for solder-joint/contact resistance, continuous current and mechanical fastening. Do not infer a current rating from their M3 size. At 15 A, each 1 mΩ produces 0.225
W. Contact resistance and local necks can dominate otherwise large pours.

CN1 is different: six BATT+ and six ground contacts are paralleled. JAE's published standard rating is 3 A/contact, with higher operation conditional on circumstances. At 15 A through this connector, ideal sharing would be 2.5 A/contact, requiring all six wired and sharing properly. In normal use it carries the high-voltage converter input current, not the 15 A low-voltage output current. Verify the exact mating housing, terminals, crimp/wire size, pin numbering viewed from each side, voltage rating and populated harness. JAE MX23A manufacturer specification

### 5. Connect AS5600 correctly and add I²C pull-ups

Confirmed fault. U801 pin 2 is on 3.3 V, while pin 1 VDD5V is marked no-connect. In 3.3 V operation pins 1 and 2 must both connect to 3.3
V. Remove the no-connect and route pin 1 accordingly. C801 = 100 nF is appropriate to retain locally for this mode. SDA/SCL lack external pull-ups in the exported netlist: add one per line to 3.3 V, initially 4.7 kΩ at 100 kHz, or select lower resistance from bus capacitance for faster operation. For example, 4.7 kΩ × 100 pF gives approximately 398 ns rise time using 0.8473RC; 2.2 kΩ gives about 186 ns.
Use a diametrically magnetized magnet, correctly centered over the sensing location, and verify field/gap and magnet-status registers across mechanical tolerances. DIR grounded is valid. AS5600 manufacturer datasheet

### 6. Drive the IR emitters independently of the visible LEDs

Confirmed inadequate transmitter architecture. GPIO4 → D601 visible LED → D602 TSAL6200 → R603 1.2 kΩ → ground, and the analogous GPIO19/D604/D605/R606 branch, place both LEDs in series on 3.3 V. Current is approximately max(0, (VGPIO − VFvisible − VFIR)/1200): little voltage remains, giving sub-milliampere or near-zero current depending on parts and temperature. Reliable detection across the opening is not established by this circuit.
Use one low-side MOSFET driver per TSAL6200, with a separate IR series resistor from the logic supply. Choose a MOSFET with guaranteed conduction at 3.3 V gate drive, gate pull-down and modest series gate resistor. A 68 Ω, 0.5 W resistor from approximately 4.7–5 V is an initial roughly 45–55 mA on-current design; verify LED forward voltage, supply tolerance and optical margin. Use separate indicators or omit them. About 50 mA on-current is a design choice, not a TSAL6200 consumption specification. Add local bypass/bulk capacitance and keep pulsed return current out of analog sensing. TSAL6200 datasheet

### 7. Remove the heavy load on the TSSP4038 output

Confirmed unsuitable loading. U601 output drives Q601 through R602 = 510 Ω and also a visible LED/R607 branch. The receiver's approximately 33 kΩ internal pull-up is not a power source for these loads. Its high level is substantially loaded; the LED is not a valid direct output load.
Connect the 3.3 V receiver output to GPIO35 directly, optionally with a suitably light external pull-up, removing Q601/R602 and the output LED load. Remove or repurpose R601 consistently. This changes the firmware polarity relative to the transistor-inverted design: receiver detection is active low. Send qualified 38 kHz bursts, at least ten carrier cycles, and evaluate missing/detected bursts with a timeout. Receiver delay is on the order of 7–13 carrier cycles. Verify the complete timing against the fastest bait passage; a constant DC LED does not exercise this receiver correctly. TSSP4038 datasheet

### 8. Make the analog IR node a sensor input rather than an

indicator driver

Confirmed sensitivity/loading issue. Q602 has R604 = 220 Ω to 3.3 V; R605 = 220 Ω and D603 also load its collector. With an illustrative red LED drop of 1.9 V, the dark node is about 2.6 V and the indicator branch draws 3.18 mA. Strong illumination can demand 3.3/220 = 15 mA from the pull-up. This wastes signal sensitivity and gives a nonlinear LED-loaded response.
Remove D603/R605 from the measurement node. Start R604 at 10 kΩ, then select approximately 4.7–47 kΩ from actual light/dark margin. With

10 kΩ, full pull-up current is only 0.33 mA. Use controlled emitter on/off sampling with ambient subtraction and time-separate the two optical channels to avoid cross-talk. For an initial slow on/off sampling scheme, C602 = 1 nF gives a 10 µs nominal RC time constant; wait at least several time constants and verify phototransistor recovery. Do not expect the original 100 nF with a 10 kΩ resistor to resolve a 38 kHz carrier. ADC readings approaching 3.3 V may saturate the useful measurement range even though the pin voltage is within the rail; use calibration/scaling or threshold detection as appropriate. TEFT4300 datasheet

### 9. Fit only the CAN termination required by the installed

bus

Confirmed duplicate termination. R701 and R702 are each 120 Ω and both populated on the same CANH/CANL pair: this board alone presents 60 Ω. With a normal far-end 120 Ω termination, the total becomes 40 Ω. For an endpoint, fit one 120 Ω resistor, preferably at the cable entry; for an intermediate node, fit neither. Mark the variants in the BOM. With the assembled bus unpowered, approximately 60 Ω across H/L is the expected result for two endpoint terminators in parallel. Add appropriate cable-interface protection and check ground offset/fault voltage; a 3.3 V CAN transceiver is not a 78 V fault-tolerant interface. SN65HVD230 datasheet

### 10. Establish regulator stability, headroom and enclosed

thermal performance

Qualification required; not a claim that the servo overloads LM1084. C302 is a 22 µF 0603 MLCC. The HTC LM1084 stability guidance specifies 22 µF solid tantalum or 150 µF aluminum electrolytic for assured operation across conditions. An MLCC with the same printed capacitance is not automatically equivalent: effective capacitance and ESR differ. Use a manufacturer-supported capacitor network or a regulator explicitly stable with the selected ceramic network, then check startup and load steps. The available HTC document lists 1.5 V dropout at full 5 A; allow D301 loss and UBEC droop. HTC LM1084 datasheet

The BL8072 is a 2 A-rated LDO, not a guaranteed 2 A output in this enclosure. At a 4.7 V input and 0.5 A on 3.3 V it dissipates approximately 0.7 W. A UBEC-fed LM1084 at about 7.1 V input and 0.5 A adds approximately 1.05 W, before diode losses. If the claimed 2–3 A electronics load includes external equipment, identify and budget it explicitly; 3 A through BL8072 exceeds its nominal capability. A switching logic regulator becomes preferable if measured heat or external loading requires it. BL8072 datasheet
Verify exact BN5A2V30 forward loss, reverse rating, package heat dissipation and surge behavior from its manufacturer datasheet before release. It has not been retrieved reliably here. These three diodes carry logic-branch current, not the full servo current. Check MLCC voltage ratings and DC-bias capacitance on all regulator rails. Add bulk capacitance at the servo connection based on measured cable inductance and supply response: C ≥ I·Δt/ΔV is a first estimate, not a substitute for a regulator that supplies sustained load. Evaluate servo regeneration and rail overshoot; capacitor size/TVS selection needs measured energy and regulator sink behavior.

### 11. Isolate programming USB power and confirm control-

signal levels

Confirmed shared USB/system power node. J3 pin 2, CH343 VDD and CH343 VBUS sense share +5V. An external programming adapter carrying host VBUS can therefore be fed by the powered board. Provide a suitable USB power-isolation arrangement and sense actual connector VBUS as required by the CH343 configuration, or define and enforce a data-only programming interface with correct VBUS sensing. Test powered/unpowered combinations. The CH343 has an internal clock source; a missing crystal is not a finding. CH343 manufacturer datasheet Confirm CN1 ARM/FEED/COMMAND signal voltage, direction, ground reference and startup state against the drone controller. ESP32 GPIO is not a direct 5 V interface; add level conversion/protection if needed. R201 provides a 4.7 kΩ COMMAND pull-down; equivalent external pulldowns are not shown for every control input. Firmware/internal pulls alone may not define the state before boot. Define a hardware-safe servo startup state, disarm default, command timeout, jam limit and recovery behavior. Check automatic programming/reset works under slow supply ramp; C203 = 100 nF with R202 = 10 kΩ gives only about 1 ms RC.
Q201/Q202 use custom CBE numbering with a correspondingly renumbered footprint. A standard SS8050 symbol/footprint substitution without checking the physical pad mapping can introduce a fault. The current mapping was inspected; the name alone is not evidence of a reversed transistor. Preserve or normalize symbol and footprint together.

### 12. Complete the raw-battery protection and insulation

review

No dedicated raw-input fuse, reverse-polarity element or surge clamp is evident on this main board. Determine which protections already exist in the drone harness/APM, then add the missing functions at system level. Specify parts from maximum continuous voltage, fault current and measured switching/hot-plug transients. Do not apply a low-voltage servo fuse or the INA180 to BATT+. Audit spacing to grounded screws, standoffs, enclosure and adjacent signal copper for the actual 78 V environment, contamination and manufacturing tolerances. A low-voltage DRC clearance setting alone does not prove this.

## Copper and mechanical assessment

Large pours are useful, but they do not establish the requested temperature rise through pads, thermal spokes, layer transitions, fuses, shunt and connectors. The saved DRC reports ten starved-thermal errors, on CN1 ground pins 14–18 on both copper layers: one usable spoke instead of the required two. Rework those local connections, refill and rerun DRC; verify solderability and current distribution. The narrow tracks visible on some supply nets include low-current branches, so their widths were not incorrectly treated as if all carried 15 A.
For a numerical screening comparison, the traditional external-trace relationship I = 0.048·ΔT^0.44·A^0.725, with A in mil², gives the following widths for nominal 35 µm copper:

Current in one external copper layer | 15°C rise screening width | 20°C rise screening width
15 A | 9.84 mm | 8.26 mm
7.5 A, assuming ideal equal sharing of15 A between two layers | 3.78 mm per layer | 3.18 mm per layer

This empirical trace calculation is not a temperature prediction for this shaped two-layer board. Equal sharing between layers requires suitable connections and similar resistance; two pours on the same net are not automatically equivalent to a single 2 oz conductor. Account for hot copper resistance, minimum manufactured thickness, nearby heat and the enclosed ambient. Use a physical 15 A thermal test for acceptance. KiCad PCB calculator documentation
The bait opening has approximately 42 mm between its straight sidewalls in the PCB geometry. The opposing digital pair's lead centers are approximately 71.0 mm apart; the analog pair's about 57.6 mm. These are placement measurements, not validated optical path lengths. Preserve the board edge and cutout until the actual casing and mechanism are registered together. The bottom-mounted encoder, servo connector and other parts need clearance to rotating gears and fasteners. The absent DXF prevents that check.
The TSAL6200 is a 5 mm leaded emitter. The custom footprint has a side-emitter name but modified geometry; check the physical right-angle lead forming, lens axis, height and mounting tolerance against the selected part. A footprint name alone does not prove incompatibility. Verify receiver/emitter polarity and optics from their package drawings, not 3D appearance alone.
Two crossing beams do not guarantee that every bait trajectory intersects a beam. Test the smallest bait, all orientations and off-center paths; add a guide or additional optical coverage if blind regions exist. Test sunlight, dust, vibration and partial obstruction. Confirm the magnet location and underside clearance using the actual assembled mechanism. None of these can be signed off from the isolated PCB STEP model.

## Current consumption: what can and cannot be estimated

The following values distinguish datasheet operating current, calculated branch current and design allowances. Servo operating current depends on load, speed, holding torque and stall duration. 7 A at 7.4 V is the owner's supplied peak estimate, not an independently verified Tiankong limit. Its 5 V stall/current/torque data remain unknown. A 15 A board capacity requirement does not mean the device normally consumes 15 A.
The current of a regulator, diode, fuse, shunt and connector carrying the same load must not be added repeatedly. Capacitors are not steady DC loads; charging/inrush and leakage are separate. With the existing linear logic regulators, the logic input current is approximately the sum of the load currents plus regulator ground current. With switching replacements, use power and efficiency instead.
Component/ reference | Current basis in current circuit | Corrected design / implication
U201 ESP32-WROOM-32E | RF TX example 239 mA average / 379 mA peak at 19.5 dBm; RX about 112–118 mA. Chip modem-sleep examples span about 20–68 mA, excluding module/board additions | Use 50 mA only as an RF-off planning example; reserve ≥500 mA capability for ESP32 supply transients. Same module remains
U202 CH343P | Manufacturer VDD operating table: 3 mA typical, 15 mA maximum; VIO supplies output loads separately, not another automatic 10 mA idle load | Keep 3 mA example; reserve 25 mA including possible VIO loading in a conservative board budget

U701
SN65HVD230

Approximately 10 mA typical / 17 mA maximum no-load
operating supply current; RS grounded means normal mode. Add dominant bus current

Proper 60 Ω bus
load at illustrative
2 V differential
adds 33.3 mA
while dominant; at
50% dominance,
example total
26.7 mA. Reserve
72 mA from 17 +
3.3/60; this is a
conservative
circuit allowance,
not a datasheet
maximum
U801 AS5600 Current configuration is invalid; do not treat measured current as valid operation. Normal- mode datasheet ceiling 6.5 mA

Budget 6.5 mA
after supply
correction; lowpower settings
require separate
timing
assessment
U601 TSSP4038 | About 0.35 mA typical, 0.45 mA maximum dark supply; illuminated/background behavior differs | Use 0.45 mA allowance for IC plus output pull-up load separately
U501 LM358 | Exact BOM manufacturer's datasheet unverified. Legacy TI LM358 figures around 0.7 mA typical / 1.2 mA maximum are provisional family estimates, not a guarantee for C18164495 | Remove for proposed current-sense redesign; INA180 supply 0.2 mA typical, 0.26 mA maximum, with small input-bias load from monitored rail

U306 BL8072 About 3 µA typical / 5 µA maximum ground current, plus all 3.3 V output load current

Same overhead if
retained; heat, not
quiescent current,
is the concern
U301 LM1084 About 7 mA typical / 10 mA maximum fixed-version ground current, plus output load; only relevant with UBEC logic path energized

Same if retained.
Zero branch
contribution
assumed for
disconnected
UBEC in APM-only mode
D602/D605 TSAL6200, R603/R606 and D601/ D604 | Each complete series branch has the same current, approximately max(0, (3.3−VFvisible−VFIR)/1.2k); likely sub-mA, not a useful specified optical drive | Two 50 mA on-current emitters at 50% duty each give 50 mA combined average; up to 100 mA if both are on. Actual duty from validated firmware
Q602 TEFT4300 and R604 | Light-dependent. With present 220 Ω pull-up, total supplied branch current ranges from the LED-loaded dark value (~3.18 mA example) toward 15 mA | With 10 kΩ, 0– 0.33 mA. Datasheet photocurrent (0.8 mA minimum / 3.2 mA typical under specified irradiation) is not a fixed supply current
D603/R605 | Included in analog branch above; approximately 3.18 mA dark example | Remove sensor-node load; optional separate indicator budget below

Q601, R601/
R602, D606/
R607

R601 collector path draws up to 3.3/4.7k ≈0.70 mA when low. Receiver high output cannot provide unrestricted base/LED current

Remove loaded
inverter and LED
branch. A 33 kΩ
external pull-up, if
used, adds up to
0.10 mA when
output low
R501/R502 Current = Vshunt/56.1k: about 12.5 µA at 7 A servo current

Remove with
LM358 stage
R503/R504 | Feedback leg current ≈Vout/56.1k; ideal 7 V operation is impossible here | Remove with LM358 stage
Q201/Q202, R202/R203/ R204 | Transient/programming loads: each 10 kΩ base resistor can carry roughly (3.3−0.7)/10k =0.26 mA; EN pull-up up to0.33 mA | Allocate 1 mA collectively; do not add transistor collector and its series resistor as separate loads
R201 4.7 kΩ | Up to 0.70 mA when COMMAND is driven to 3.3 V, generally supplied by the controller output | Include in system interface budget; not automatically from board regulator
R701/R702 | Bus termination current already included in CAN calculation, not extra consumption per resistor | One fitted only at an endpoint; no double counting
Added I²C pull-ups | Absent currently | Two 4.7 kΩ pull-ups draw at most 1.40 mA together when both low; use actual bus duty for average

Optional
corrected
visible
indicators

Existing four LEDs counted in their branches above

Allow 2 mA each,
up to8 mA total,
on independent
drivers/resistors if
all retained
D301/D302/
D303

Carry the respective logic current; loss = I·VF, reverse leakage unknown until exact datasheet verified

Do not add
carried current
again; account for
loss and junction
heat
F1/F2, shunt 0.501, J1/J2/ CN1, U302– U305 | Carry load current; contact/ fuse/shunt heat = I²R | No independent idle draw. Replacement resistance/current ratings must be included in voltage-drop and heat budget
C201–C206, C301–C304, C601/C602/ C701/C801 | Approximately zero ideal steady DC; actual leakage and dynamic charging depend on exact capacitor | Include effective capacitance, startup inrush and transient currents in regulator checks
J3, TP401/ TP402, H101– H106 | No intrinsic DC load | External programmer/load can change power flow; mechanical holes and test points do not consume current

APM and
external UBEC

Output current is loaddependent; input quiescent current and efficiency curves not supplied

APM20 A is
capability. Exact
UBEC10 A is
capability and is
unsuitable for this
input. Use
measured
conversion losses
for battery budget
Tiankong
H20/35 servo

Owner estimate: peak ~7 A
at7.4 V. Running/holding/stall duration and5 V current
unknown

Retain supplied
peak for
preliminary sizing;
obtain exact
manufacturer data
and measure
installed
mechanism

Current references: Espressif module, ESP32 chip, CH343, CAN, AS5600, IR receiver, phototransistor, BL8072, HTC LM1084, provisional TI LM358 family reference.

Worked planning totals

These are explicitly scenarios, not measured consumption or guaranteed worst-case limits. The original circuit has faults, so its figure describes nominal powered electronics rather than successful operation.

Scenario, excluding servo | Original nominal circuit | Recommended corrected circuit
RF off, ESP32 assumed50 mA; CAN50% dominant at2 V differential; encoder6.5 mA; USB IC3 mA | About0.10 A on APM logic path | About0.14 A with two emitters averaging50 mA combined, corrected analog node and pull-ups

Same, but ESP32 TX
average239 mA
About0.29 A | About0.33 A

Conservative supplycapacity allowance
including transients and
uncertain small loads
0.65 A | 0.75 A

Original worked example uses40 mA for CAN with the unintended40 Ω total bus load (one external120 Ω assumed), analog3.2 mA, LM3580.7 mA, TSSP0.35 mA and about2 mA other loads. Corrected example uses26.7 mA CAN, INA1800.2 mA, analog0.33 mA, TSSP0.45 mA, emitter average50 mA and3 mA miscellaneous/pull-up allowance. Optional indicators add up to8 mA. UBEC operation through LM1084 adds approximately7–10 mA to input current, plus its voltage-dependent power loss. These examples deliberately exclude unidentified external2– 3 A loads.
For preliminary sizing at the supplied7 A servo peak, the existing linear architecture would need approximately 7.65 A, and the corrected design budget 7.75 A, at the low-voltage converter output. This assumes the logic branch is fed from that same source. The original circuit is not capable of using that current correctly; its shunt would dissipate4.9 W. The corrected estimate is below10 A but does not make the specified UBEC compatible with78 V or15 A continuous.
At5 V, use Iservo(5 V) + up to0.75 A; do not assume the7.4 V peak also describes5 V. If15 A means the total converter output, reserve0.75 A for electronics and14.25 A for servo/external load. If15 A must remain available to the servo alone, size the source for at least15.75 A plus the relevant margin.
Battery current must be calculated by power. For a hypothetical suitable7.4 V converter retaining the linear logic branch,7.75 A output at78 V and assumed90% efficiency gives7.4×7.75/(78×0.90) ≈ 0.82 A input, plus any converter idle current omitted by that efficiency assumption. At15 A servo plus0.75 A logic, the same calculation gives about 1.66 A. The5 V APM at15.75 A output gives approximately 1.12 A under the same illustrative efficiency. Battery current rises as battery voltage falls. These are not APM efficiency guarantees, and the unsuitable10A UBEC is not endorsed by the calculation.

## Automated check results and release conditions

Original ERC: 81 findings, dominated by custom-library/pin-type issues, plus the missing LM358 B unit. Original PCB DRC: 75 findings, including 10 starved-thermal errors, 0 unconnected items, and 46 separate schematic-parity findings concerning datasheet fields. The46 metadata mismatches are not46 proven connectivity faults. Library/footprint mismatches require review because some custom numbering is intentional; do not blindly overwrite footprints from standard libraries. Six padstack warnings concern paste reduction on F1/F2 and the shunt; resolve for intended stencil or document hand assembly. Silkscreen/text warnings are lower priority than electrical and thermal errors. Some checks were disabled in the project; zero unconnected items is not a complete manufacturability pass. See the saved JSON reports for exact locations.
Before a functional release:
1. Implement the circuit corrections in a new electrical revision; keep schematic, PCB and both assembly variants consistent. Regenerate manufacturing outputs only after this work. The annotated review copy supplied here has not implemented them.
2. Obtain the missing exact component and mechanical information, complete pin/package and insulation checks, and resolve all substantive ERC/DRC findings. Preserve the casing outline unless an agreed mechanical change is made.
3. Bring up logic on a current-limited low-voltage supply first. Verify every rail, programming, encoder communication/magnet status, CAN termination and control-signal levels before attaching the servo or raw battery.
4. Measure servo running, starting, holding and brief jam currents at both permitted voltages. Verify current-sense scaling against an independent instrument; demonstrate prompt, safe jam handling without brownout or unintended movement.

5. Load-test each intended15 A path to thermal equilibrium inside the actual enclosure, at worst ambient. Measure copper, contacts, fuses, shunt, standoffs, regulators and wiring. Require copper temperature rise ≤15–20°C and every component within its own derated limits. Measure rail sag/overshoot during servo steps. A copper temperature target does not mean regulator junctions may rise only20°C.
6. Test source selection and all powered/unpowered/programmer combinations for backfeed. Check raw-input startup/hot-plug and transient protection with appropriate test equipment and limits.
7. Register the DXF/casing/gear assembly to the PCB; verify component heights, magnet gap, sensor axes and swept gear clearance. Run both bait sizes across the full opening, with sunlight/dust/vibration and worst speed, logging missed/double counts and sensor faults. Confirm disarmed and lost-command behavior in firmware.
The highest-priority functional path is to qualify the5 V APM build, correct current sensing, AS5600, IR and CAN circuits, and upgrade the complete high-current path. The7.4 V option additionally requires a replacement converter suitable for18S/78 V and the specified continuous load.

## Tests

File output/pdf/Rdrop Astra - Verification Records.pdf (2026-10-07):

RDROP ASTRA | GPT6 REFINED | 6 OCTOBER 2026 | 1

# Verification records

Recorded results from the KiCad 9.0.7 refinement. This PDF presents verification.json in readable form; it does not represent a new hardware test.

## Preservation checks

Check | Recorded result
Footprints and pad-net assignments | PASS - unchanged
Outline and cutouts | PASS - unchanged
Schematic files (byte comparison) | PASS - unchanged

## Original versus refined

Metric | Original | Refined
Copper layers | 2 | 2
Footprints | 78 | 78
Vias | 299 | 339
DRC errors | 0 | 0
DRC warnings | 80 | 80
Unconnected items | 0 | 0
Schematic-parity issues | 0 | 0
Ground filled area - F.Cu (mm²) | 6140.365979 | 6876.470360
Ground filled area - B.Cu (mm²) | 6822.951752 | 7399.303023

## PCB file fingerprints (SHA-256)

Original PCB

c80d10d69f5310de7cd80b0fb0a269ae44d5f7d4dcedefd1dde41fcfe5b25da2

Refined PCB

c66dce7ed199feca08d3f7f59ac46b55a2c05673bc01c735b9433585a8296aa0

Limits: configured DRC and geometry checks do not qualify 15 A peak operation or the 15-18 °C temperature-rise target. Peak path, duration and repetition remain outstanding.

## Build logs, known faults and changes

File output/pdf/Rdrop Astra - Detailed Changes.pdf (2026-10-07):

RDROP ASTRA | GPT6 REFINED | 6 OCTOBER 2026 | 1

# Detailed changes

KiCad engine: 9.0.7. Complete readable register of changes.json. UUIDs identify objects in the PCB file.

# Ground-zone changes

Zone UUID | Layer | Clearance before / after (mm)
a0eae8ca-36b8-4c27-901c-011db39c70fb | F.Cu | 0.8 / 0.3
e51d2154-5fba-4386-a8ed-fa0b8de98b01 | B.Cu | 0.8 / 0.3

# Pad connection

### J301 pad 1 | Net: GND | Connection: solid

Eliminate isolated thermal spoke after ground refill; maintain continuous supply return.

# Register totals

22 accepted trace-width changes; 40 added GND vias; 7 rejected trial width changes restored to original widths.

No components were moved or removed. Outline, cutouts and schematic connections were preserved. This register documents geometry changes; it does not establish measured thermal or electrical performance.

# Accepted trace changes

Wider segments retained after clearance validation. Lengths are shown to six decimal places.

Track UUID | Net | Before / after width (mm) | Length (mm)
31ef5721-37c4-4afb-a183-91e3dbcd6aab | +5V_2 | 1.0 / 1.5 | 1.430000
8fe0f9db-3934-486b-b89d-d72e3d65f1bd | +5V_2 | 1.0 / 1.5 | 5.552900
1d886611-bd6e-4bd3-89fa-fe7d860c1dc4 | +5V_2 | 1.0 / 1.5 | 4.875000
6a4d7f8d-76c3-4099-9ecd-1760d642f191 | +5V_2 | 1.0 / 1.5 | 0.728320
c228a6d9-6566-492a-9b8f-61c2f1f1c938 | +5V_2 | 1.0 / 1.5 | 1.428356
ddcf7a62-9421-440f-ab91-25352fdc545b | +5V_2 | 1.0 / 1.5 | 13.590000
38a982f1-31e3-4093-b7da-6f7d5a66890a | +5V_1 | 1.0 / 1.5 | 12.525000
7b42af86-8700-4ae5-87a2-bdae6c66ada5 | +5V_1 | 1.0 / 1.5 | 7.276129
0c479267-2ed6-4ae2-a3ff-444148215c8c | +5V_1 | 1.0 / 1.5 | 1.682914
3e047d4c-6501-4dee-a039-87f970b2bc88 | +5V_1 | 1.0 / 1.5 | 0.721249
79876056-91ae-4bd8-a9f7-9bf3e1b5d42d | +5V_1 | 1.0 / 1.5 | 1.343503
8b07e27b-5b8e-47e0-a421-9c9188633edd | +5V_1 | 1.0 / 1.5 | 0.862670
a100604c-2fe2-4a07-bb8b-b0f2b73a4795 | +5V_1 | 1.0 / 1.5 | 6.127500
af8104fb-2127-4010-826c-19c26e32aef8 | +5V_1 | 1.0 / 1.5 | 0.025000
b49ec555-dbeb-4bc7-8021-23aae4556453 | +5V_1 | 1.0 / 1.5 | 7.110000
be5ffec7-982b-4e36-9b7a-fda47f46750c | +5V_1 | 1.0 / 1.5 | 36.420000
ea8b7dc0-9f6a-40dc-a41f-a371bb869255 | +5V_1 | 1.0 / 1.5 | 0.042426
f1580c28-4462-418c-a6aa-7755514cde45 | +5V_1 | 1.0 / 1.5 | 2.900000
32cc0a4c-58c2-4bfb-bd9e-dc7f79261db2 | +UBEC_OUT | 0.8 / 1.2 | 0.992500
c2030e9c-479f-4819-afa8-48d06526600c | +UBEC_OUT | 0.8 / 1.2 | 2.973384
59d9cac1-4bbb-4a7c-98b0-3134c5ca3544 | +UBEC_OUT | 0.8 / 1.2 | 3.719382
86840676-2275-4376-aa27-94664568face | +UBEC_OUT | 0.8 / 1.2 | 1.535000

# Added ground vias

All 40 vias connect GND between F.Cu and B.Cu. Coordinates and dimensions are millimetres.

Via UUID | X | Y | Diameter | Drill
4f058209-c8e0-4b9f-b7aa-72ac596e9f02 | 190 | 104 | 0.8 | 0.4
5103b338-409e-489a-b3b5-4ae4d1853f16 | 190 | 110 | 0.8 | 0.4
a6444da1-77a7-4621-9709-567f652d4c49 | 190 | 116 | 0.8 | 0.4
252e0d64-be67-4016-a4a2-41b4f9598200 | 190 | 122 | 0.8 | 0.4
d03ba79b-2f0c-4446-963f-7663e0cc5c0d | 190 | 134 | 0.8 | 0.4
b4dd7a33-aef1-4a96-b11f-eeef50c902d8 | 190 | 140 | 0.8 | 0.4
f5109881-d996-41fa-a389-535b86e29b68 | 190 | 146 | 0.8 | 0.4
1c30795d-1eeb-4a58-a370-36d789f87e49 | 190 | 164 | 0.8 | 0.4
d711969d-a0b2-45cb-bb32-4528ecd0d391 | 190 | 170 | 0.8 | 0.4
da337b94-2b8e-43b0-8fa6-fed4939105ff | 196 | 104 | 0.8 | 0.4
a62c1e2c-7fc4-4343-b256-057f18a1f4e2 | 196 | 110 | 0.8 | 0.4
7e1838f3-ef65-4b3e-8d48-edabee23e854 | 196 | 116 | 0.8 | 0.4
ed7dad48-4d0a-41ae-8c1c-96bab078ccab | 196 | 122 | 0.8 | 0.4
03dadaa3-797c-4d17-ba16-51785dd43cf3 | 196 | 134 | 0.8 | 0.4
bf96cb1e-32a4-4a60-a619-a5ad34a8ed71 | 196 | 140 | 0.8 | 0.4
7a7d458e-08df-4d22-8090-dac7046168c6 | 196 | 146 | 0.8 | 0.4
ab091ba1-f8e1-4725-9f13-990401a697a5 | 196 | 158 | 0.8 | 0.4
0c003798-fe19-4071-bedf-bb88ac67e76c | 196 | 164 | 0.8 | 0.4
6c04c590-fe63-46f1-a685-370f970ca067 | 202 | 110 | 0.8 | 0.4
05e15dcb-8308-4fa4-a1a2-068f5a53d24d | 202 | 134 | 0.8 | 0.4
02cf8eac-71b3-4944-8bb9-82d6eb872edf | 202 | 140 | 0.8 | 0.4
83f1908e-48be-4d0c-8dcb-c7663d5c295d | 202 | 146 | 0.8 | 0.4
a4af87c3-5e21-49e6-a645-8c971389039f | 202 | 158 | 0.8 | 0.4
d937447c-dd04-42aa-90ed-05df7d6025d4 | 208 | 158 | 0.8 | 0.4
beb62826-1421-4f06-a1d8-d84699df7e99 | 208 | 170 | 0.8 | 0.4
27d15ff4-b6c6-47e1-a1b9-44a07a532ed2 | 214 | 140 | 0.8 | 0.4
afaafc92-153c-4351-af02-d25854cb5626 | 214 | 170 | 0.8 | 0.4
852bd6c5-30c3-4aae-9d8b-77855ad1a145 | 220 | 128 | 0.8 | 0.4
8d4ed9b1-c5d5-4d54-adae-d1c710ec256d | 226 | 116 | 0.8 | 0.4
747cefeb-d623-4cd5-b31c-3fa29de4c4db | 232 | 116 | 0.8 | 0.4
e33ae8e0-2945-475b-8e82-2f20a26c2bb5 | 232 | 128 | 0.8 | 0.4
25e6cc08-bdda-4d24-be4a-bb8f0fb3299d | 232 | 170 | 0.8 | 0.4
b35144c2-46f7-4b66-b311-5689b9287cce | 238 | 146 | 0.8 | 0.4

Via UUID | X | Y | Diameter | Drill
8337b717-4951-42d9-9adb-6c621894dd49 | 238 | 170 | 0.8 | 0.4
eba2fa26-b37a-4e66-8c9e-c4def7609f1d | 244 | 122 | 0.8 | 0.4
23c66fe4-8d05-4c6a-a3c4-d33e21650c0b | 244 | 152 | 0.8 | 0.4
38231787-8827-4f4f-aed7-17a2558a775c | 244 | 158 | 0.8 | 0.4
cbd844e1-5888-4da9-8527-a3061e860717 | 250 | 164 | 0.8 | 0.4
d236f57e-b7d1-4b3a-99c8-a516b9ed016c | 280 | 170 | 0.8 | 0.4
69ed1ec7-236f-429c-b66a-0b829ff3a820 | 292 | 158 | 0.8 | 0.4

# Rejected trial changes

These proposed width increases did not pass clearance checks and were reverted. The after values below are rejected trial values, not the final board widths.

Track UUID | Net | Before / after width (mm) | Length (mm)
33dcc04a-68da-46ac-abc9-14f14b844d02 | +5V_2 | 1.0 / 1.5 | 3.068000
d59b67b2-0072-4cc7-8c16-a5a8bba0c551 | +5V_2 | 1.0 / 1.5 | 5.400000
f29ac1e3-2c80-4949-89cc-0f2107b0e8a6 | +5V_1 | 1.0 / 1.5 | 1.819800
109b701d-eebe-41b2-a856-4d2e9f344b4c | +5V_1 | 1.0 / 1.5 | 6.140000
317e9d76-75eb-488f-90a4-51a9b8c9a45b | +5V_1 | 1.0 / 1.5 | 8.686807
432518a4-6154-4fb2-a027-37da3119bf04 | +5V_1 | 1.0 / 1.5 | 8.950000
42cd3acf-8253-40e7-8f70-5f27f708a503 | +UBEC_OUT | 0.8 / 1.2 | 21.855000

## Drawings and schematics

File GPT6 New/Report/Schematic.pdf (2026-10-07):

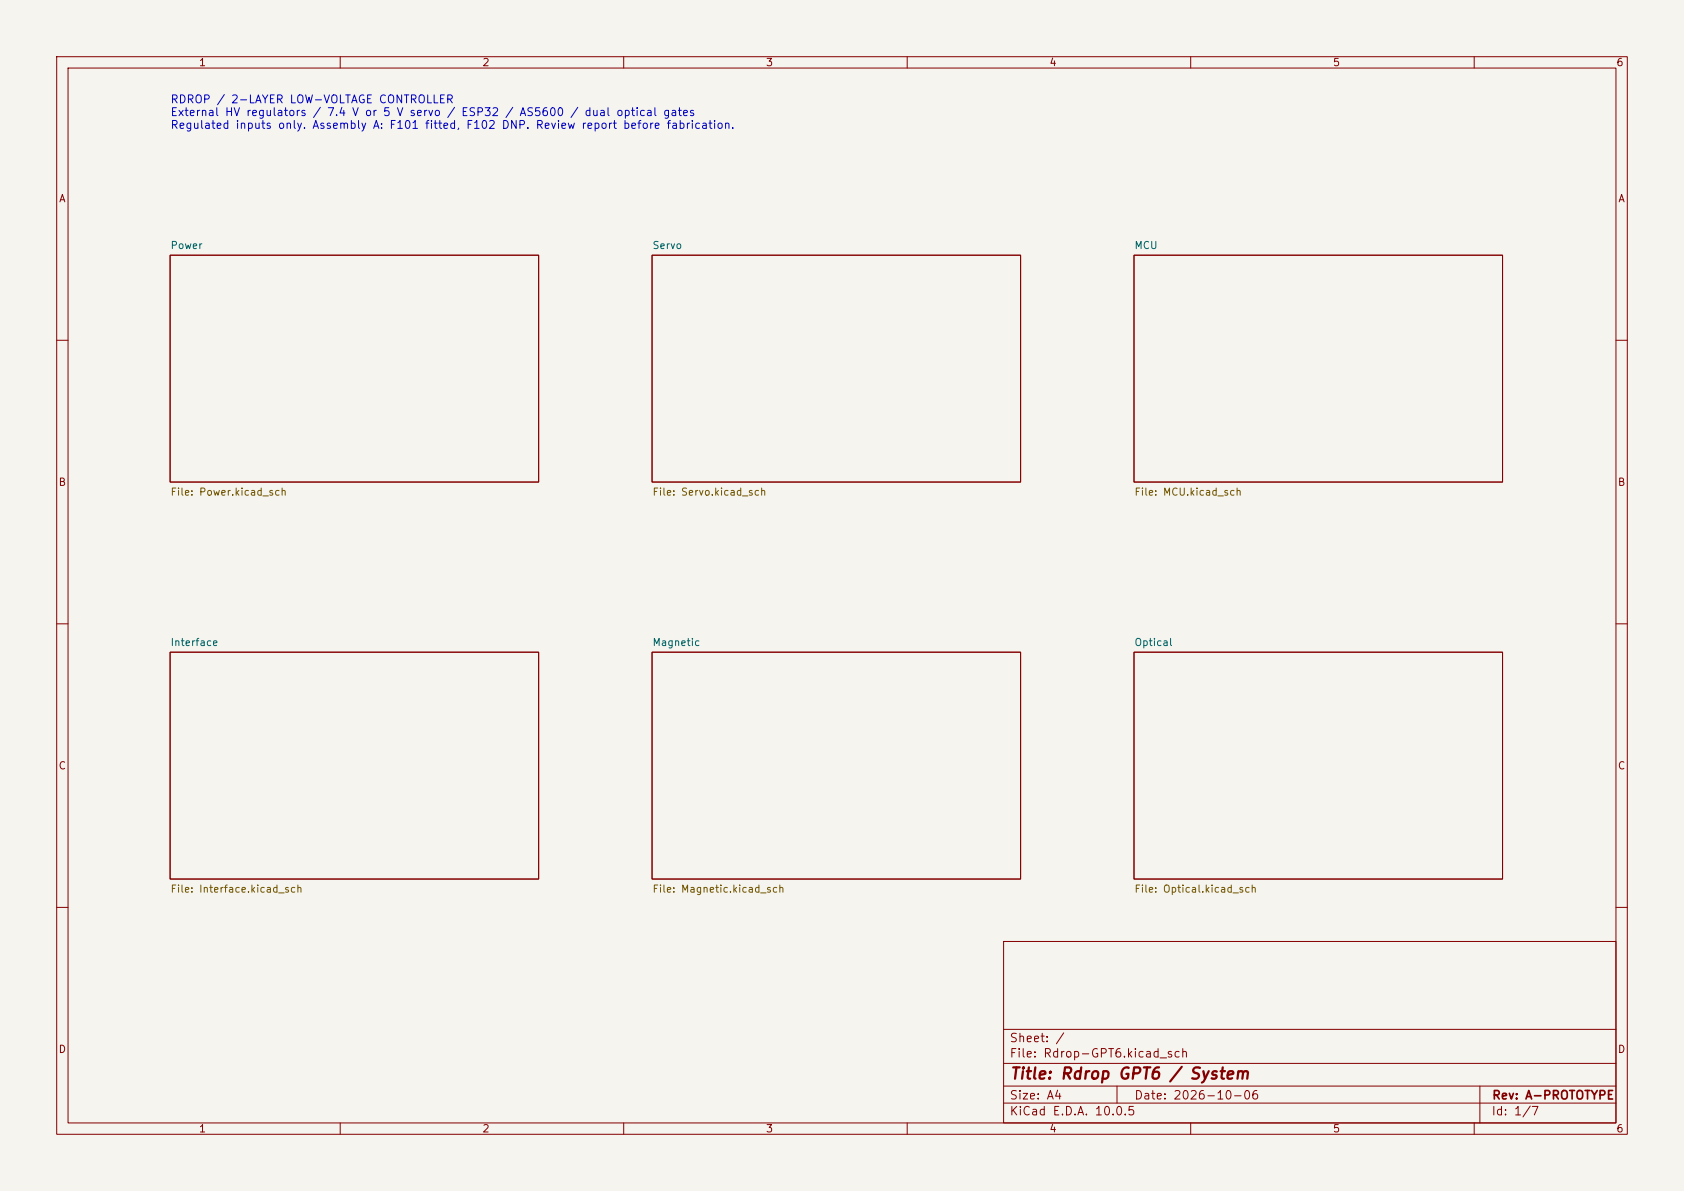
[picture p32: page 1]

RDROP / 2-LAYER LOW-VOLTAGE CONTROLLER
External HV regulators / 7.4 V or 5 V servo / ESP32 / AS5600 / dual optical gates
Regulated inputs only. Assembly A: F101 fitted, F102 DNP. Review report before fabrication.

Size: A4 | Rev: A-PROTOTYPE
KiCad E.D.A. 10.0.5 | Id: 1/7

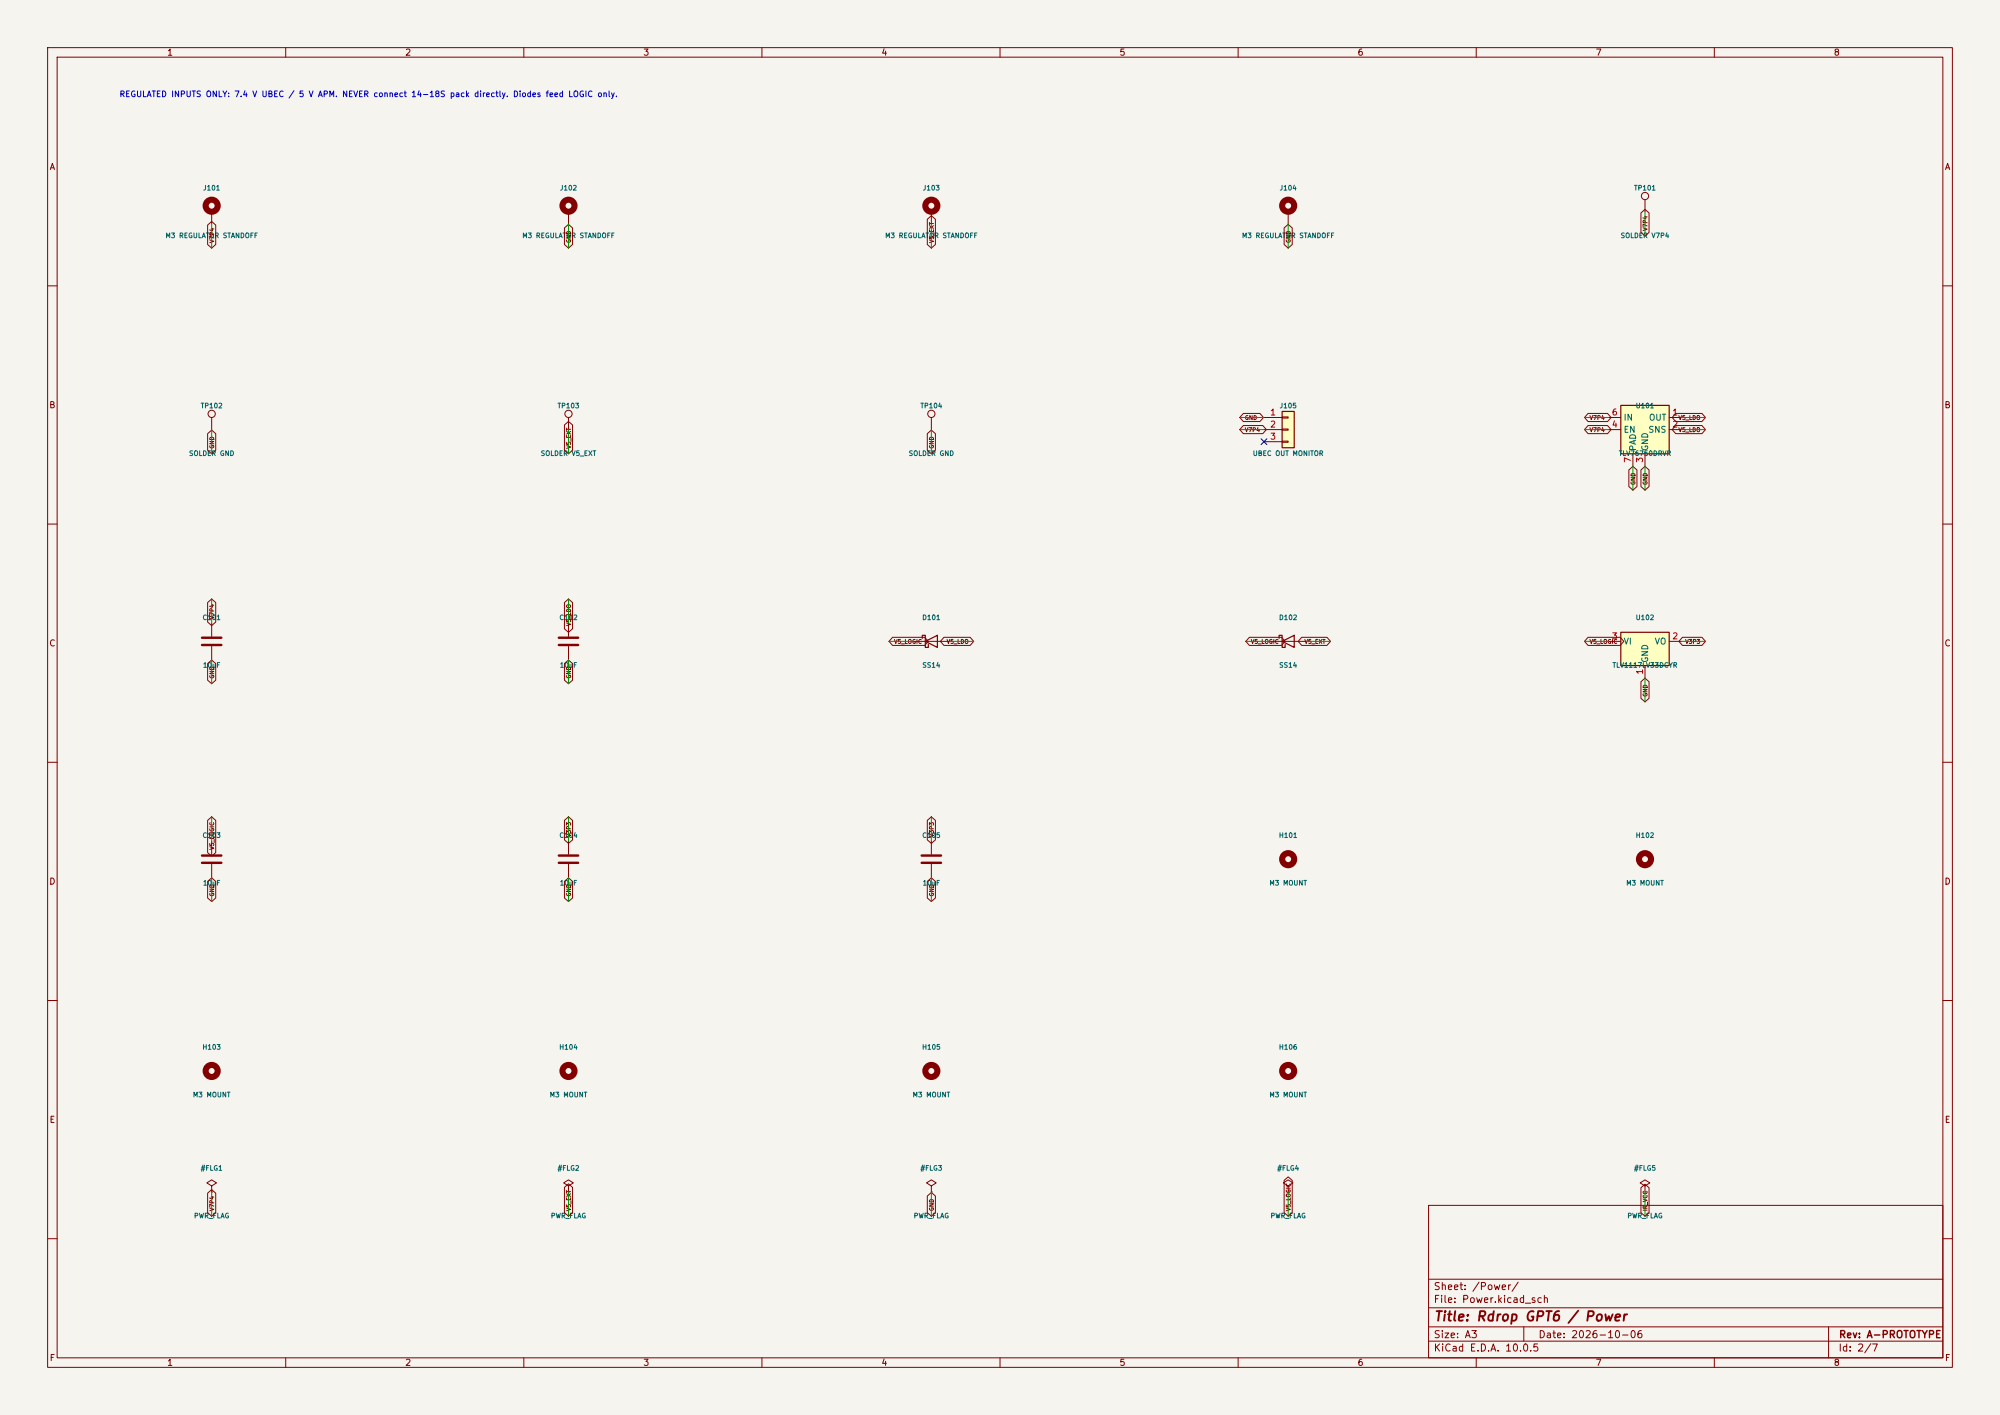
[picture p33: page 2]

REGULATED INPUTS ONLY: 7.4 V UBEC / 5 V APM. NEVER connect 14-18S pack directly. Diodes feed LOGIC only.

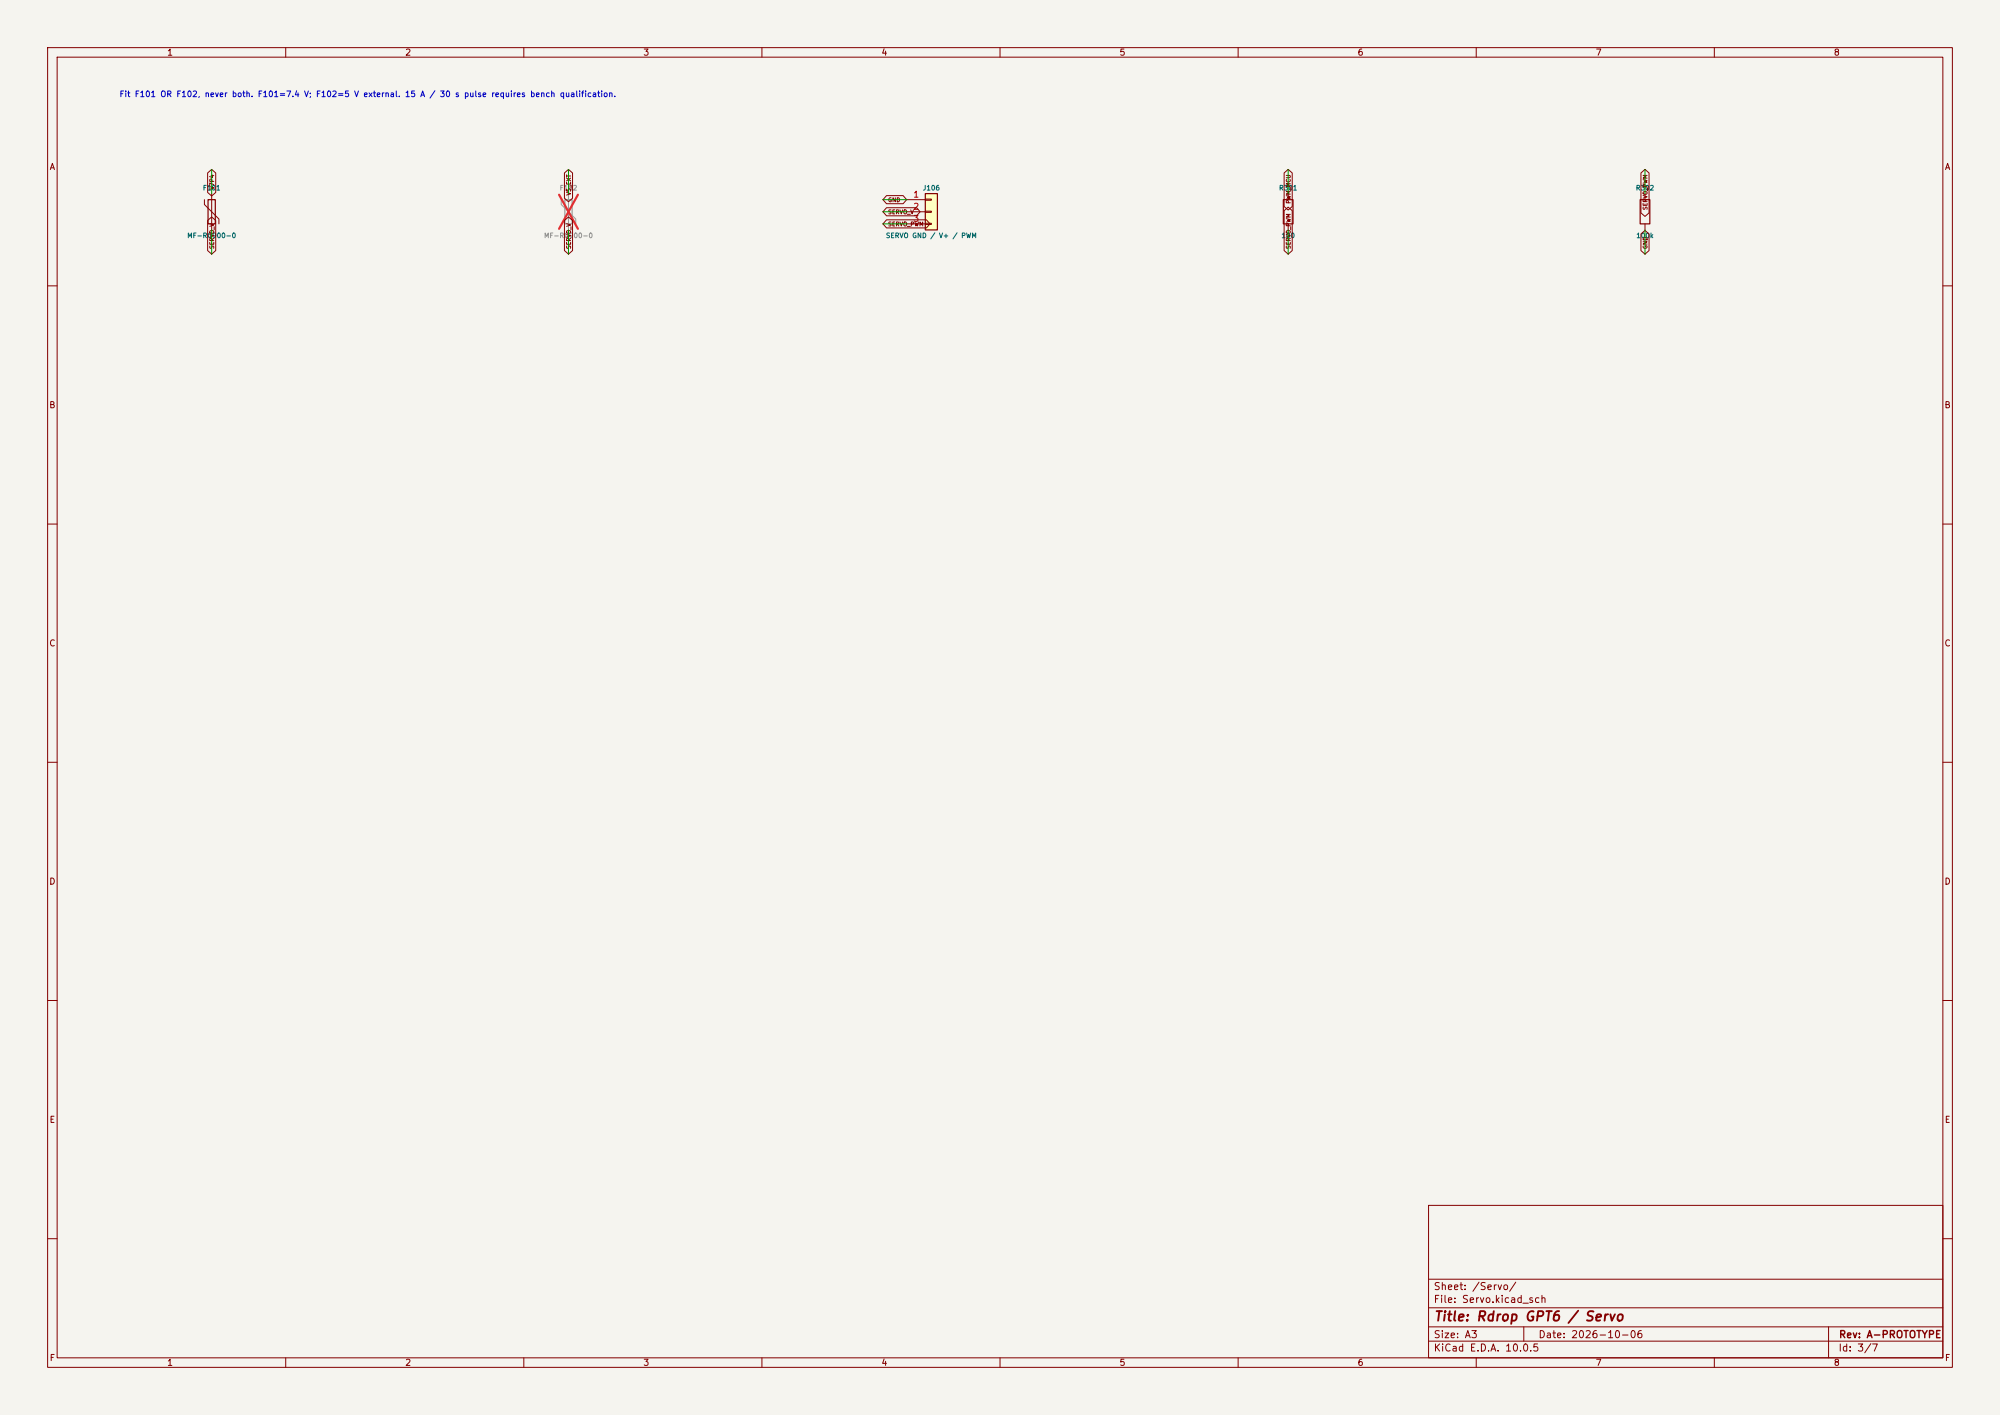
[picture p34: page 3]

Fit F101 OR F102, never both. F101=7.4 V; F102=5 V external. 15 A / 30 s pulse requires bench qualification.

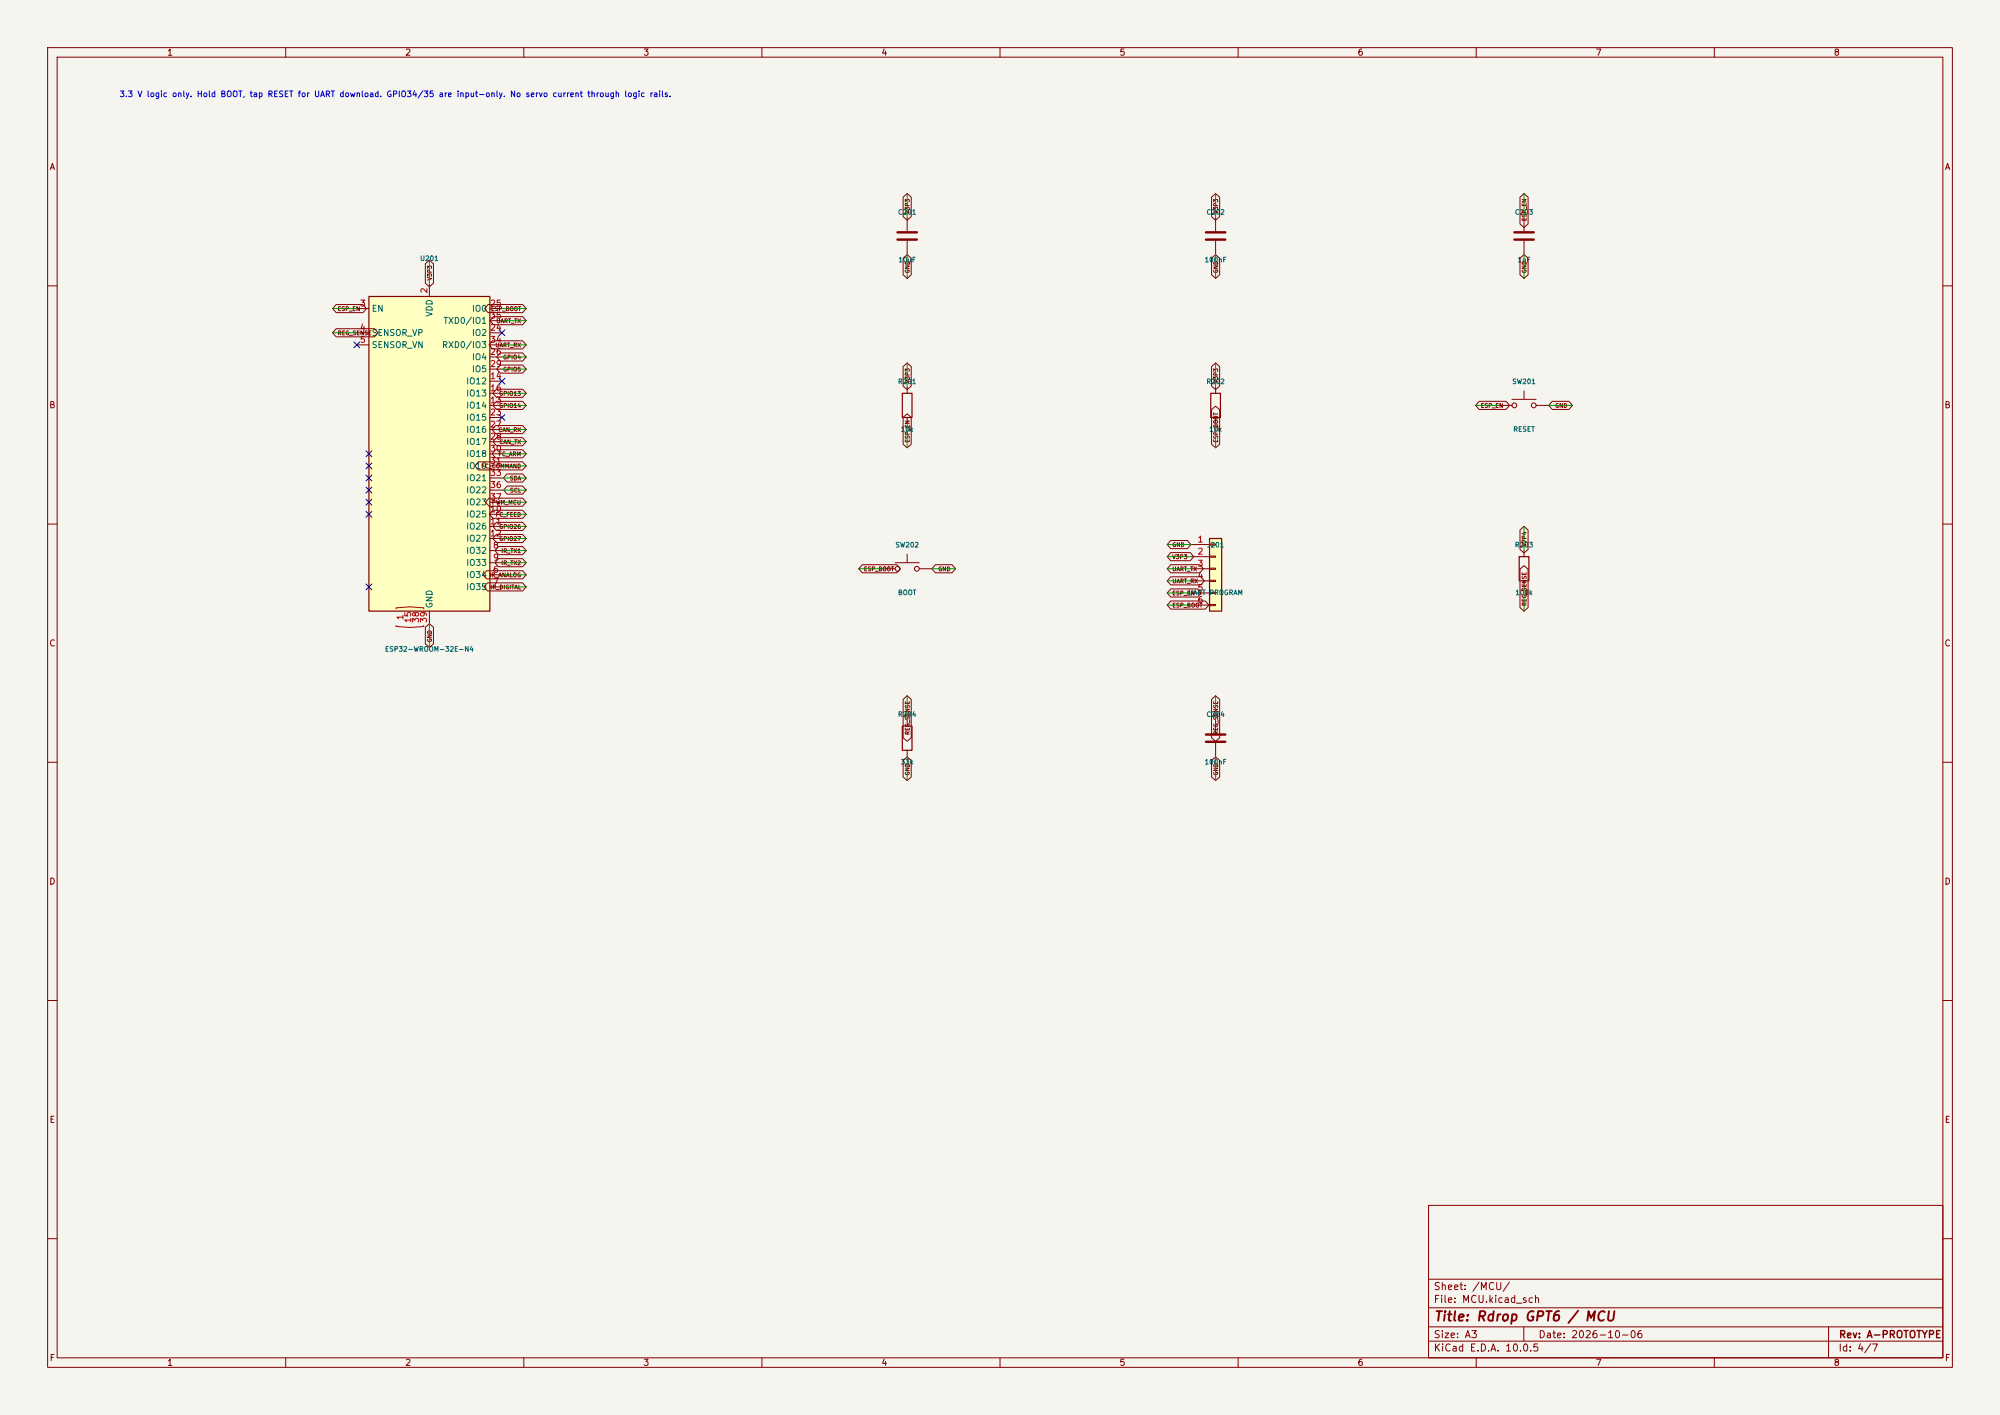
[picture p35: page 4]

FC_ARM 3.3 V logic only. Hold BOOT, tap RESET for UART download. GPIO34/35 are input-only. No servo current through logic rails.

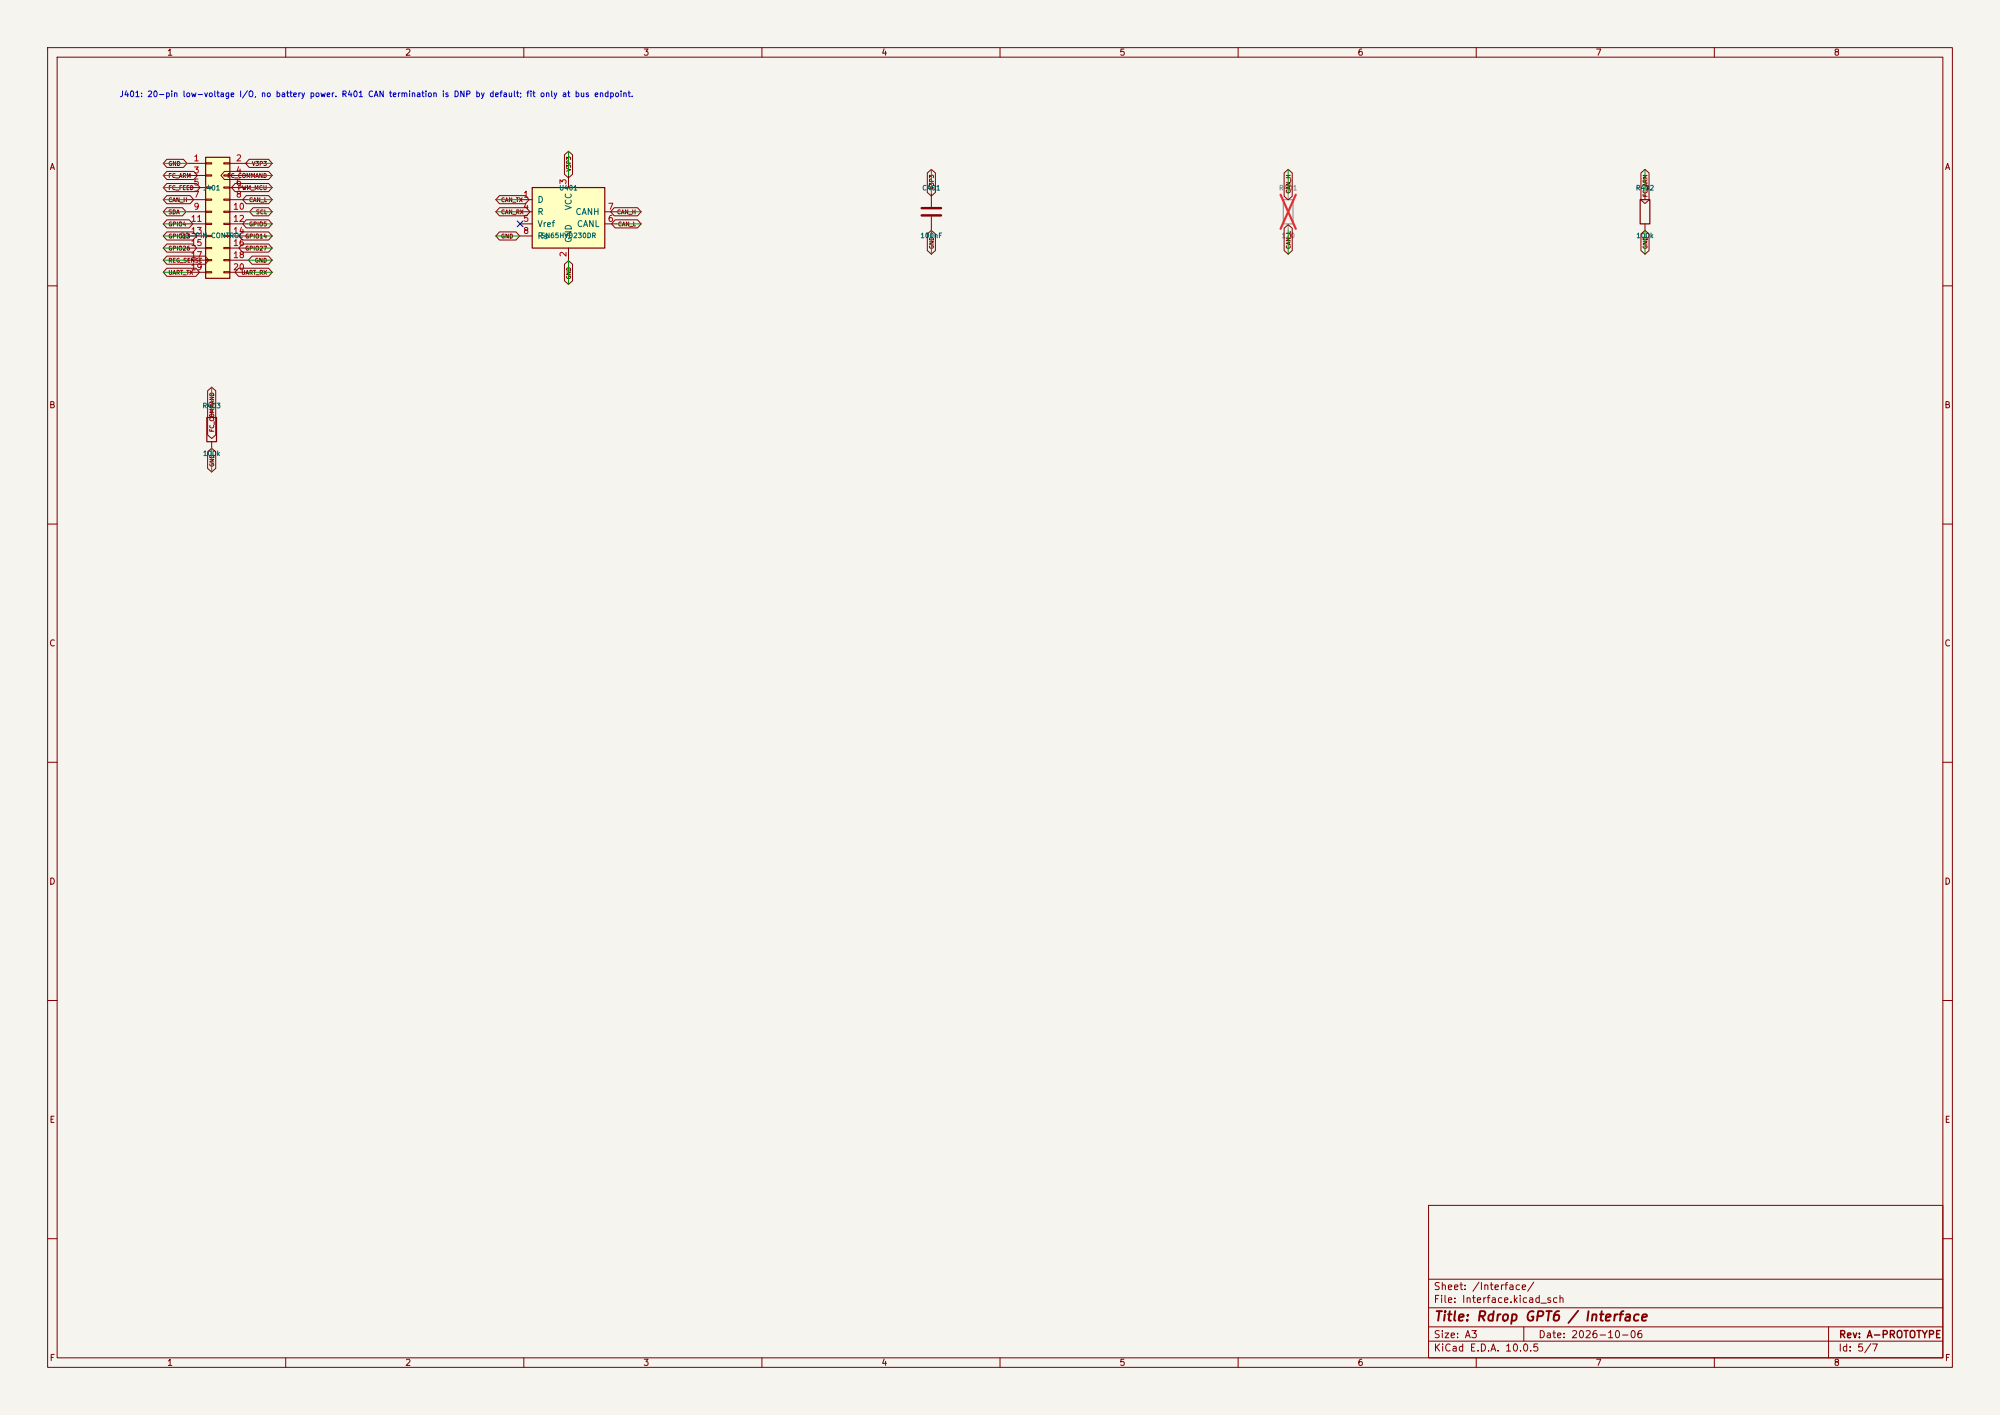
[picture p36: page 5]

J401: 20-pin low-voltage I/O, no battery power. R401 CAN termination is DNP by default; fit only at bus endpoint.
GPIO5 FC_COMMAND

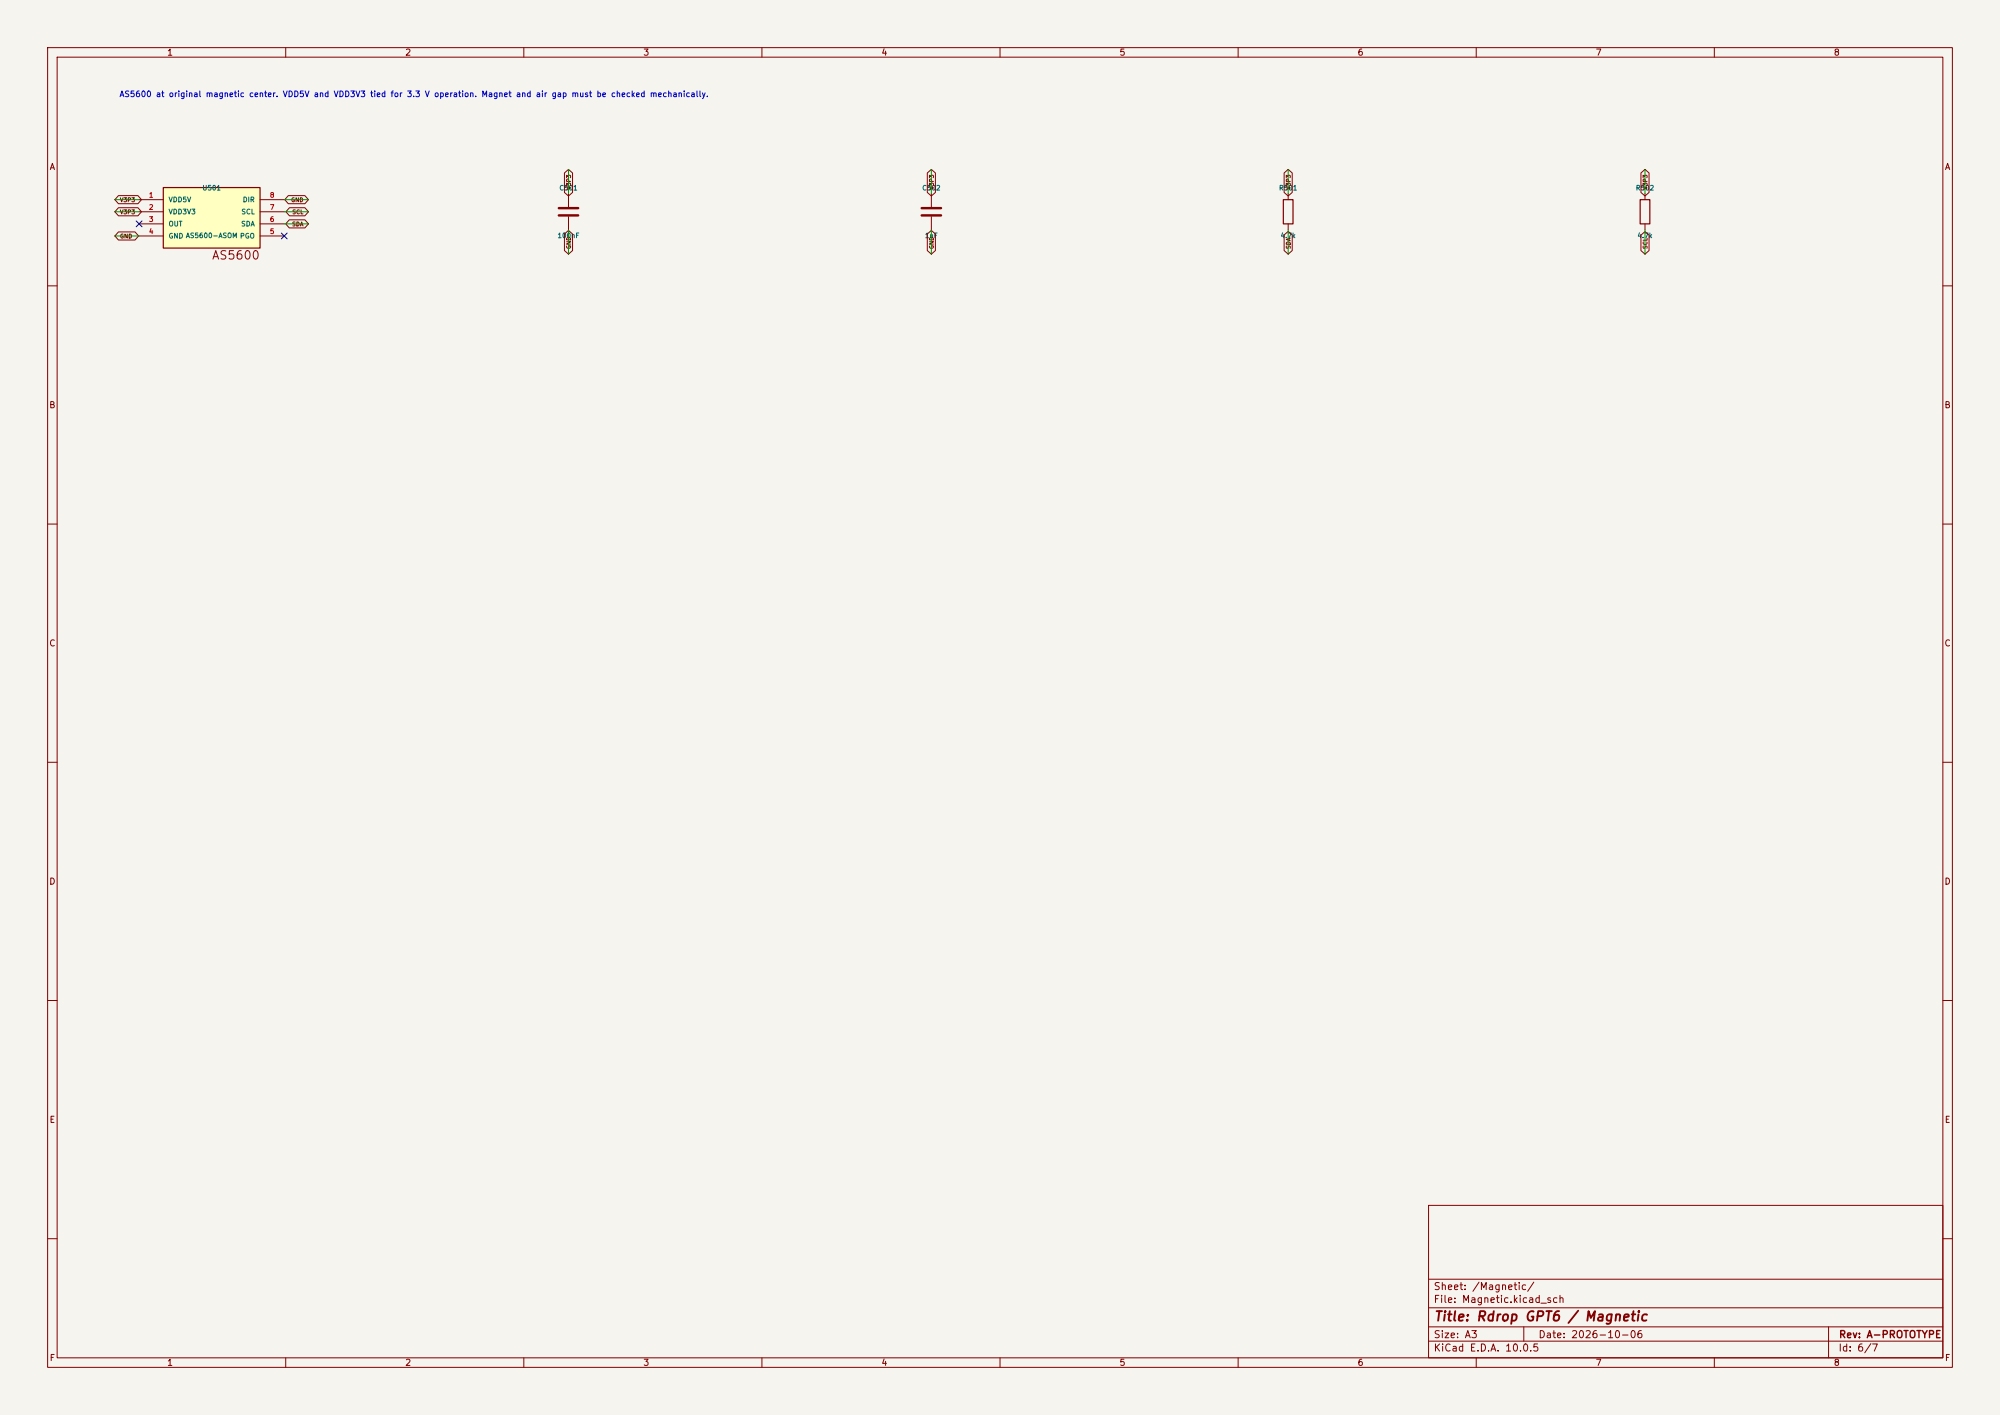
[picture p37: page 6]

AS5600 at original magnetic center. VDD5V and VDD3V3 tied for 3.3 V operation. Magnet and air gap must be checked mechanically.

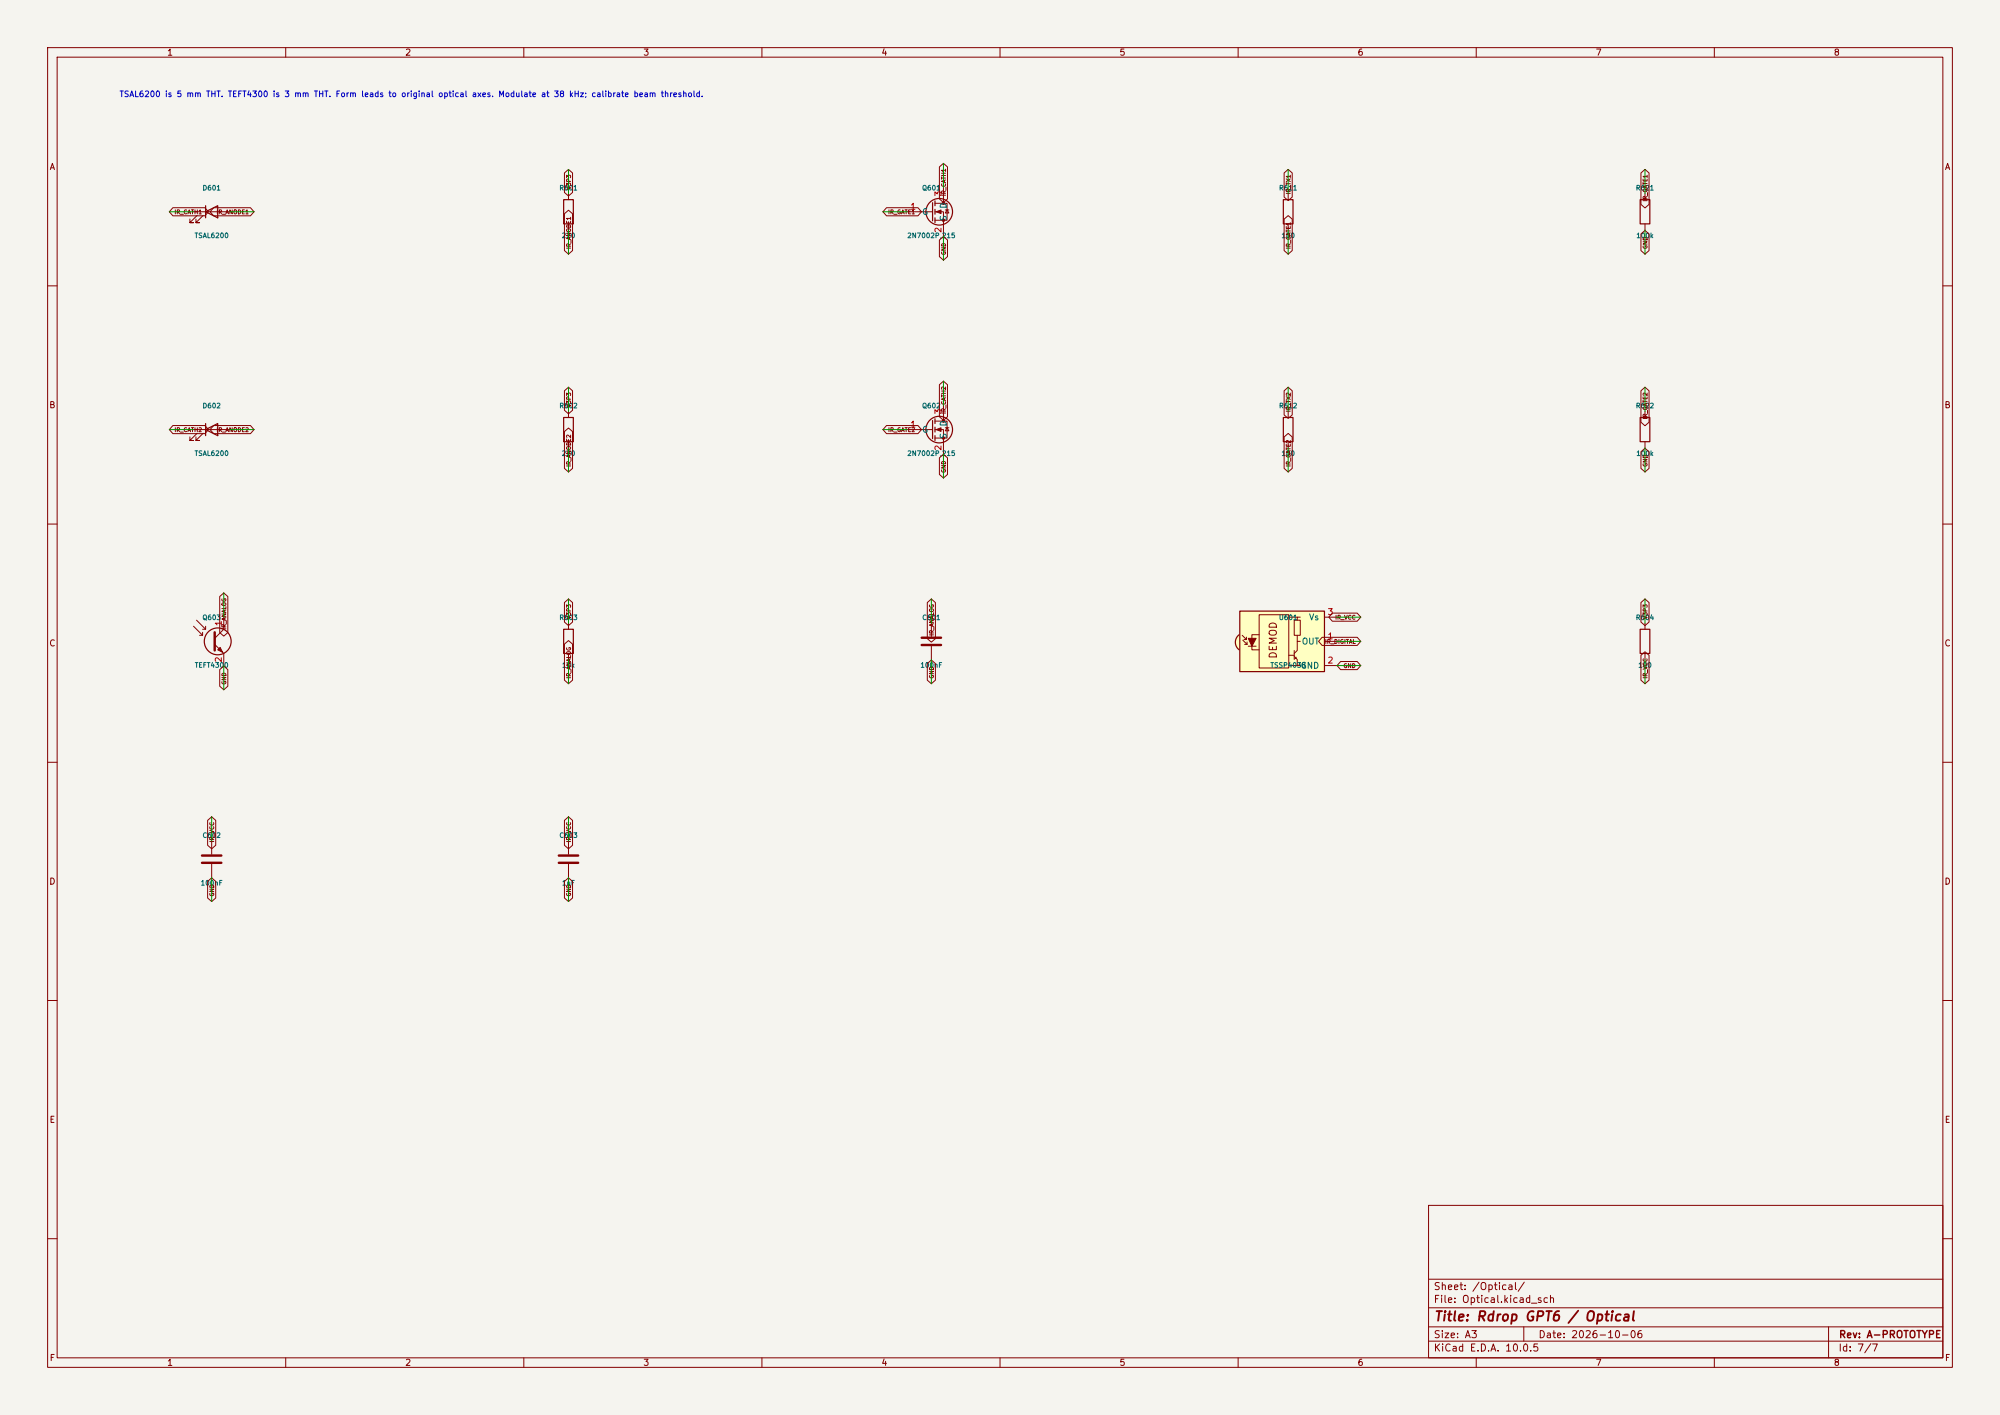
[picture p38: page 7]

TSAL6200 is 5 mm THT. TEFT4300 is 3 mm THT. Form leads to original optical axes. Modulate at 38 kHz; calibrate beam threshold.

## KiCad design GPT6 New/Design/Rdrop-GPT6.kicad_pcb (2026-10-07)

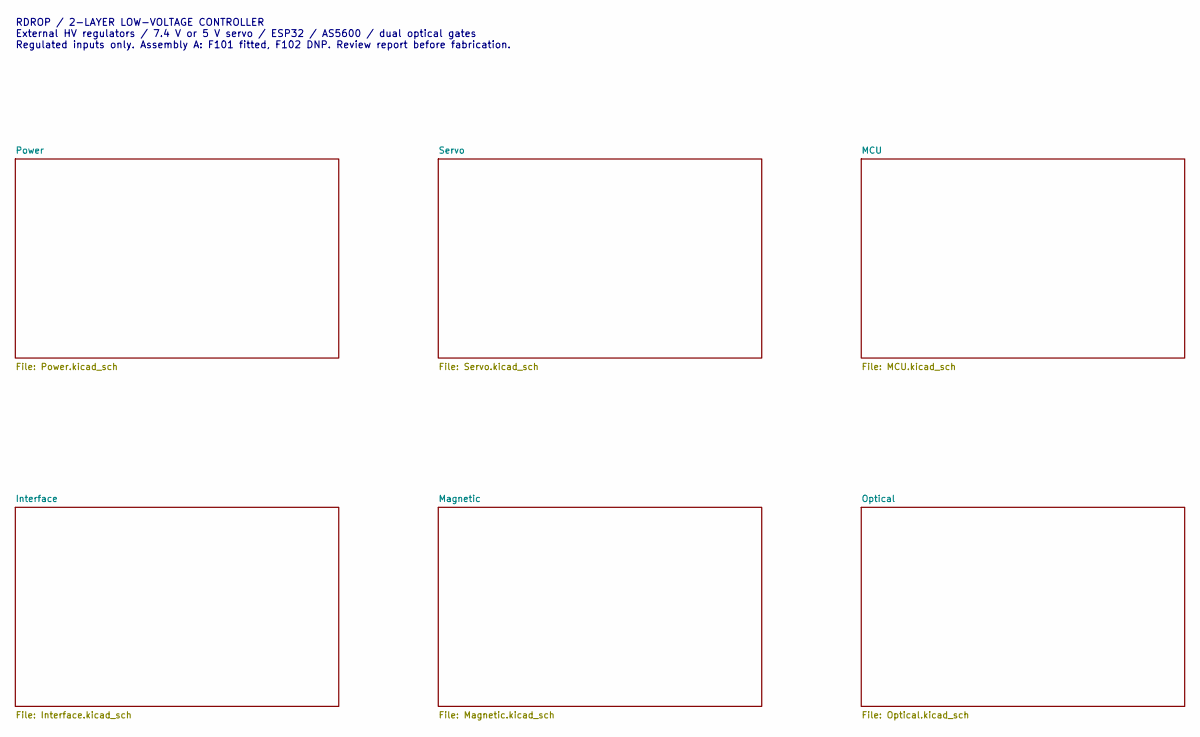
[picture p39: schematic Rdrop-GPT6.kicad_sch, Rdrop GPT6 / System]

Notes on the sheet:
RDROP / 2-LAYER LOW-VOLTAGE CONTROLLER External HV regulators / 7.4 V or 5 V servo / ESP32 / AS5600 / dual optical gates Regulated inputs only. Assembly A: F101 fitted, F102 DNP. Review report before fabrication.

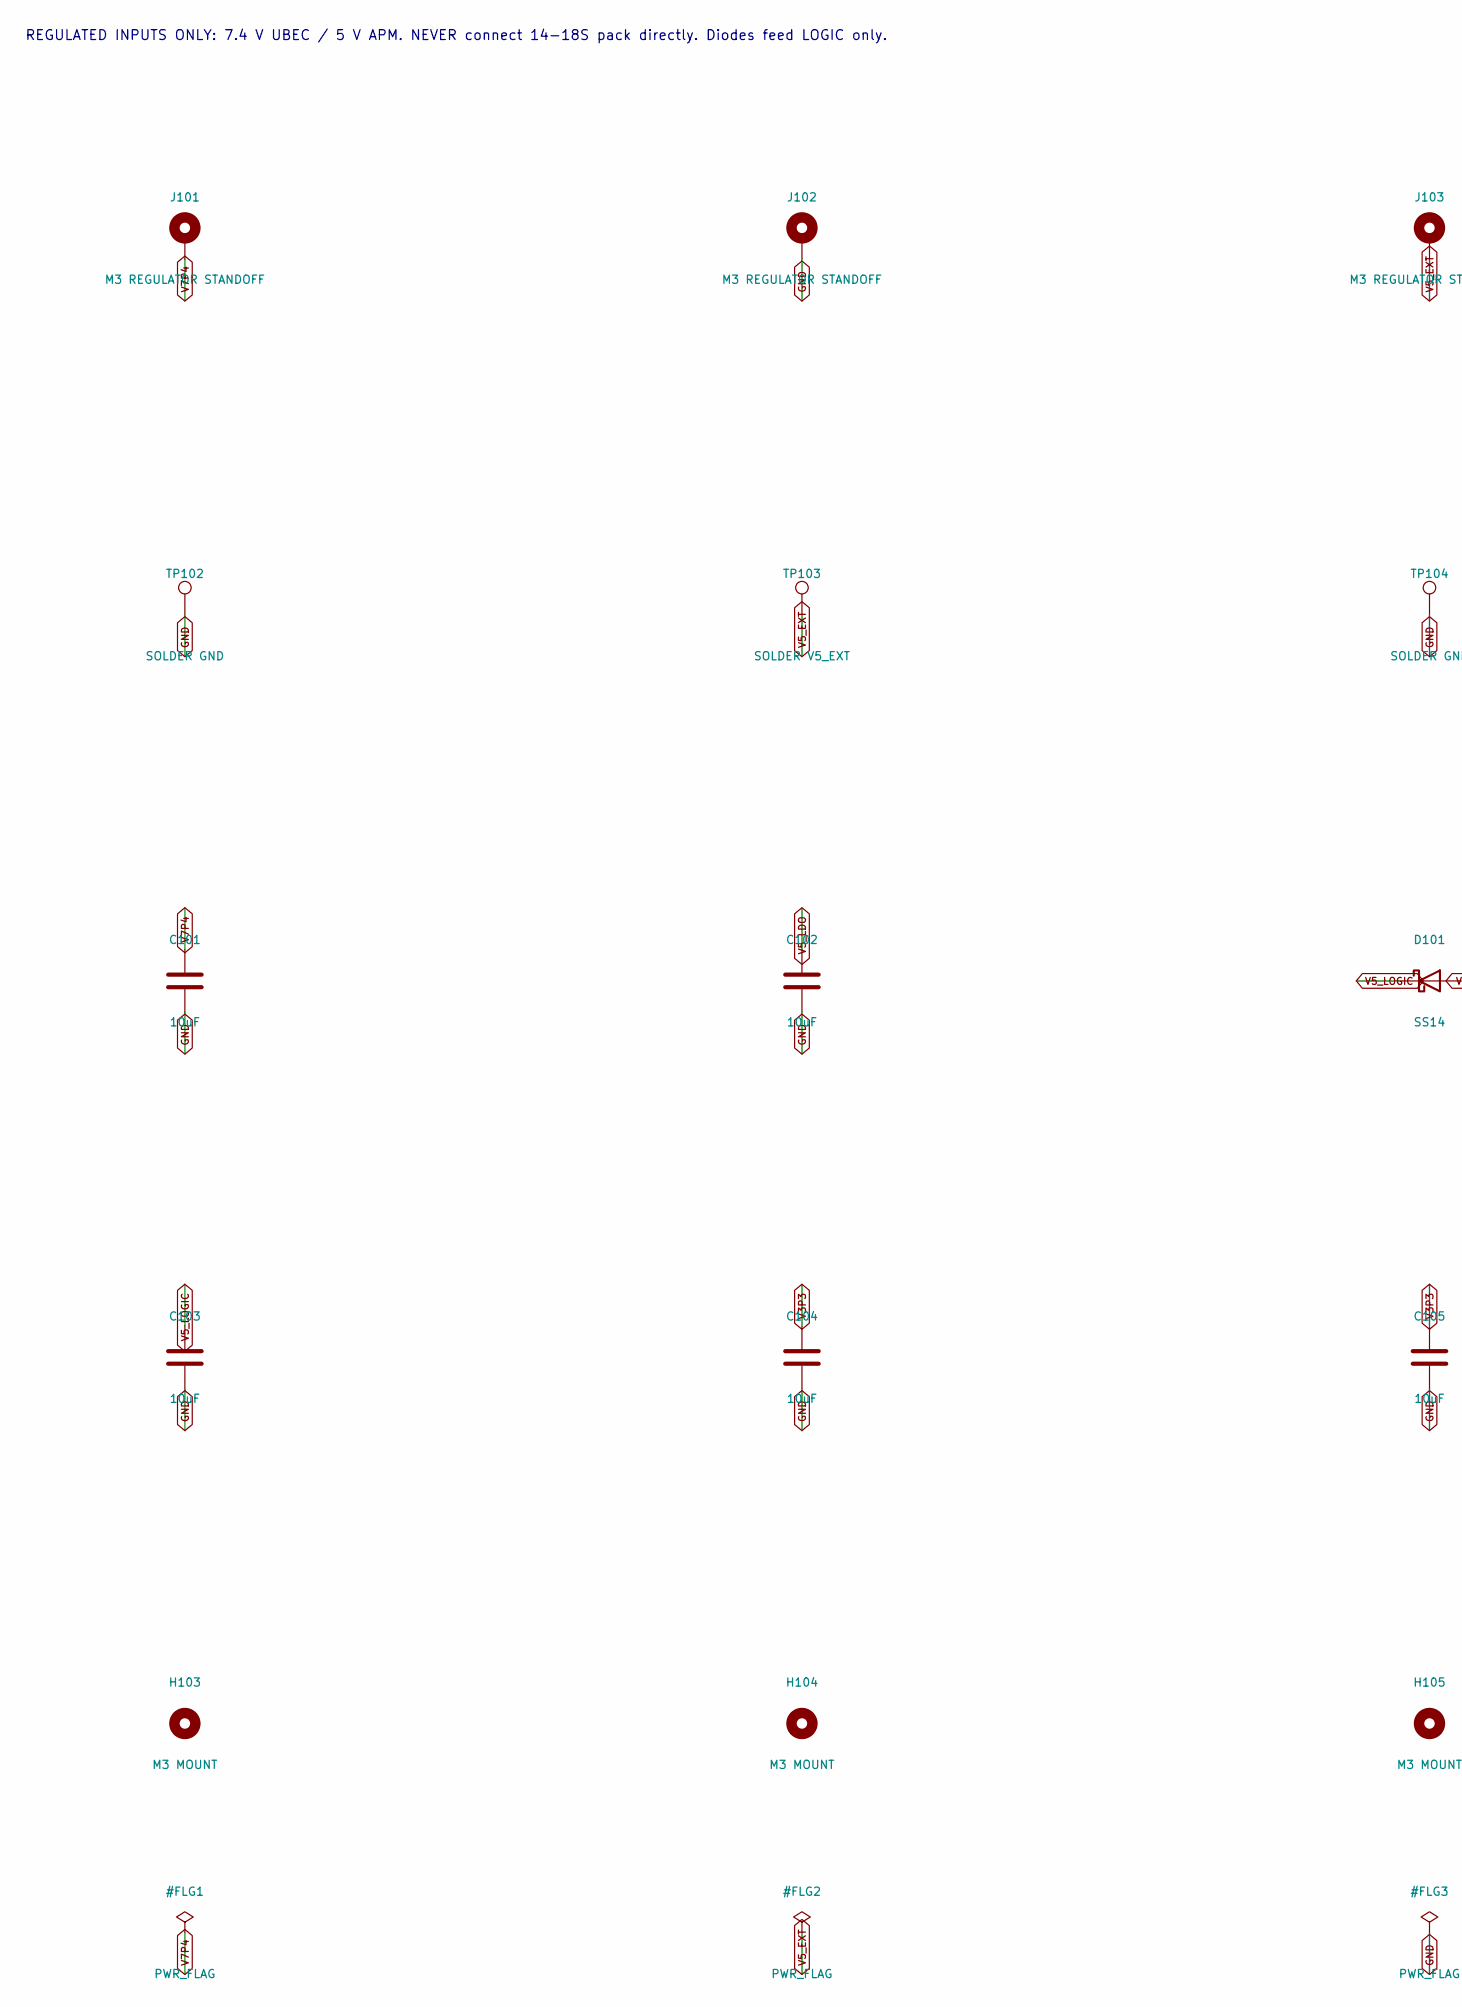
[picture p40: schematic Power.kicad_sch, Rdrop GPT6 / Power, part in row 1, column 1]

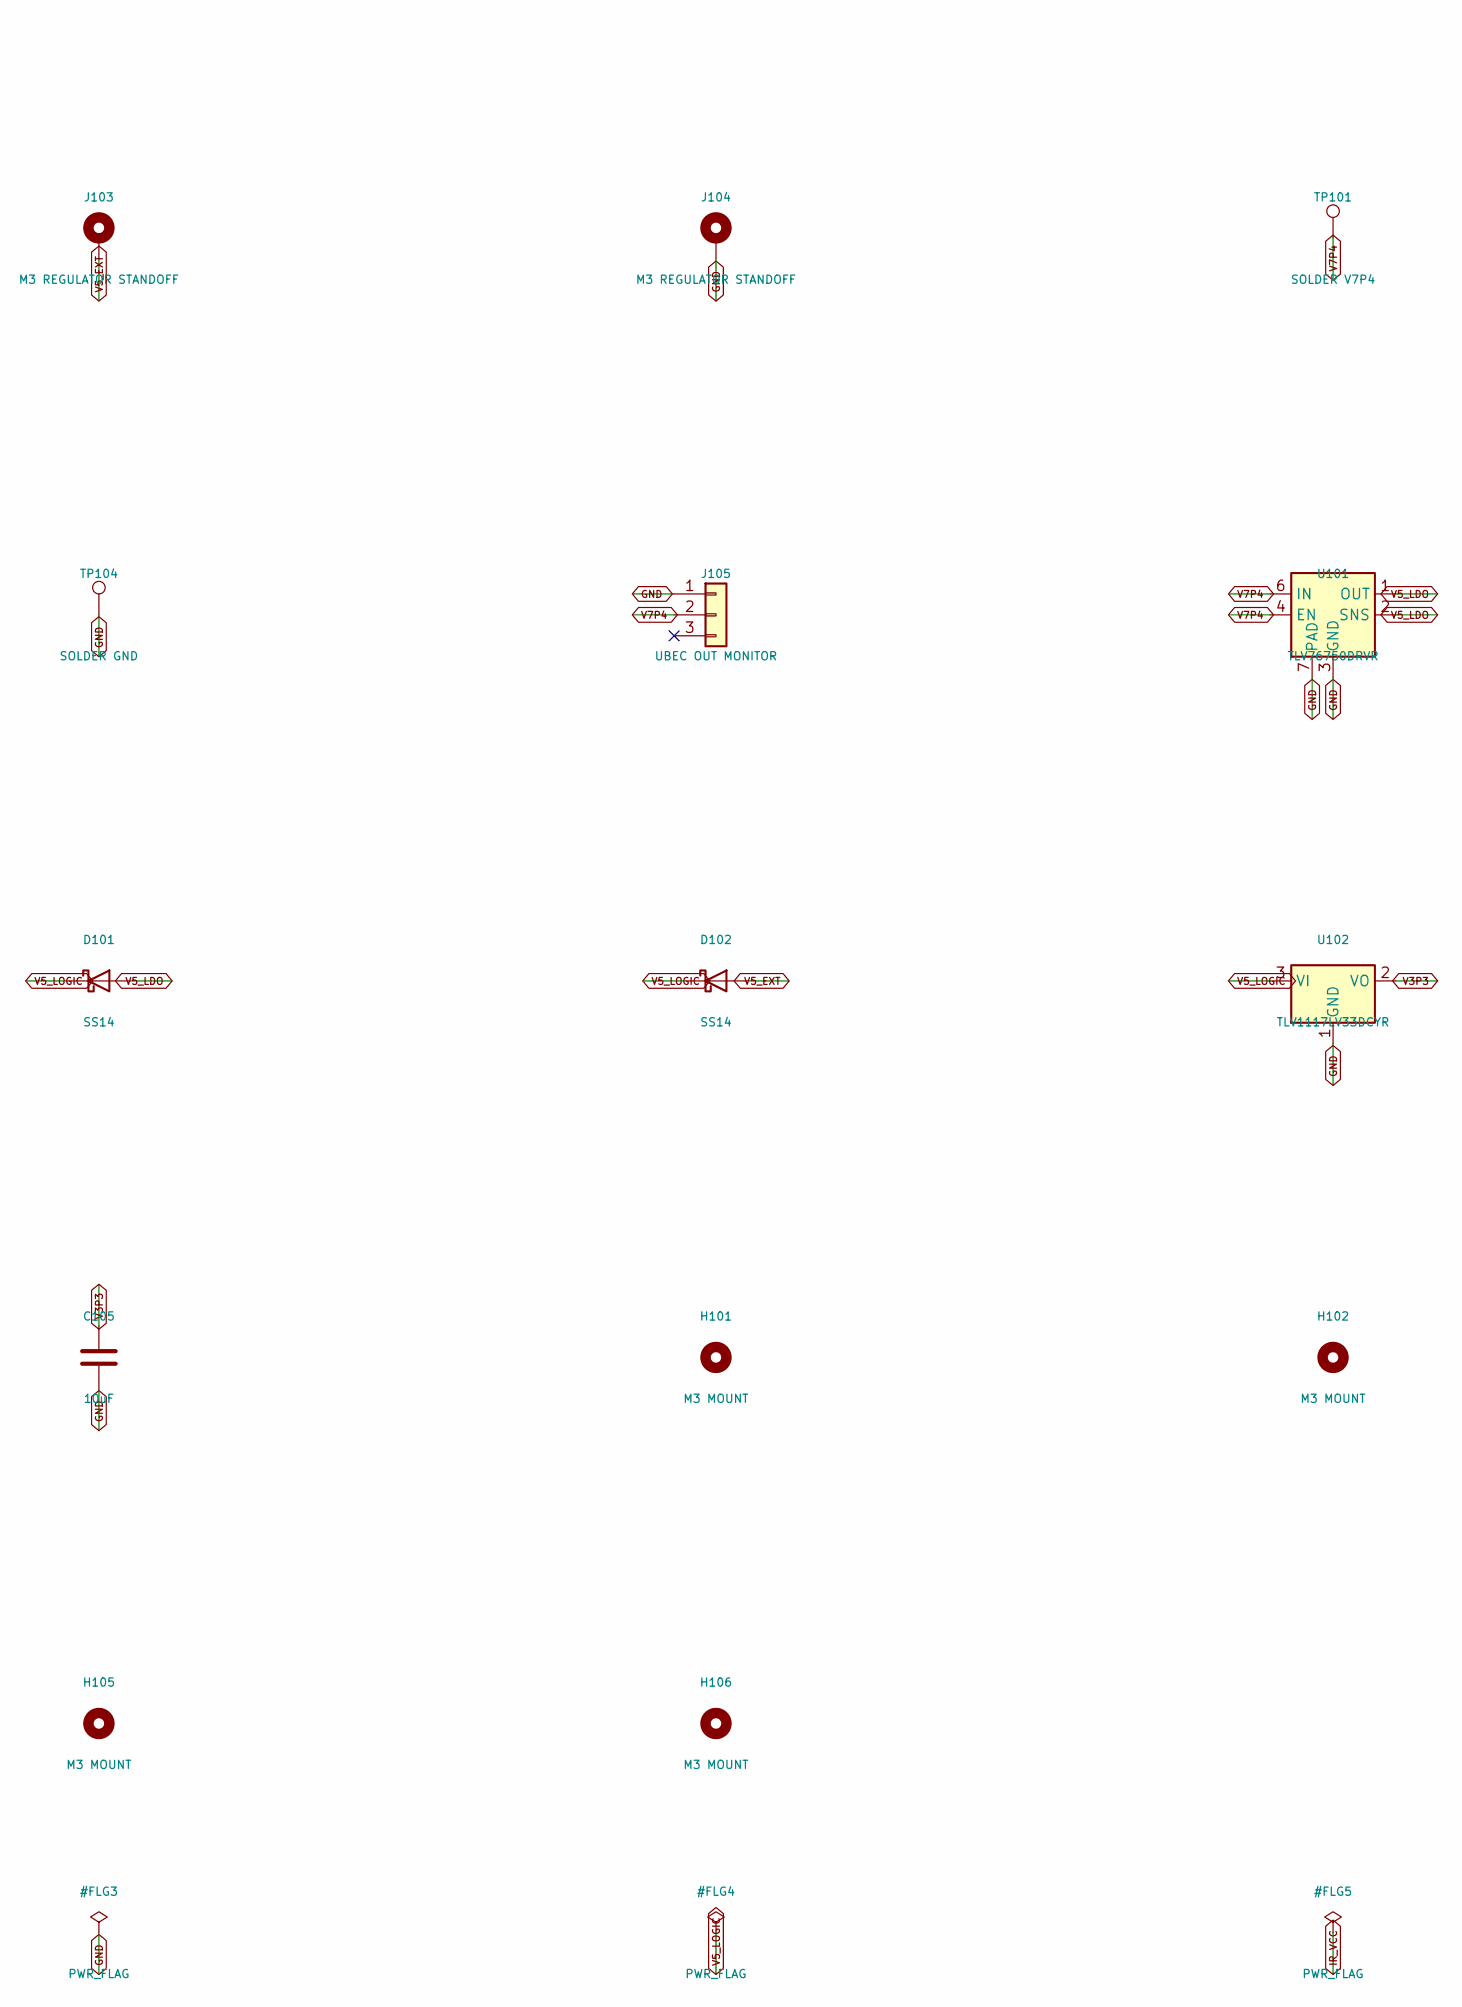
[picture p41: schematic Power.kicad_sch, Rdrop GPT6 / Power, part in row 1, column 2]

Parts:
C101, C102, C103, C104, C105: 10uF; C_0603_1608Metric; MPN GRM188R61C106KAALD
D101, D102: SS14; D_SMA; MPN SS14-E3/61T
H101, H102, H103, H104, H105, H106: M3 MOUNT; MountingHole_3.2mm_M3; MPN M3_HARDWARE
J101, J102, J103, J104: M3 REGULATOR STANDOFF; Mounting_Wuerth_WA-SMSI-M3_H10mm_9774100360; MPN 9774100360R
J105: UBEC OUT MONITOR; PinHeader_1x03_P2.54mm_Vertical; MPN TSW-103-07-G-S
TP101: SOLDER V7P4; TestPoint_Pad_D4.0mm; MPN WIRE_PAD
TP102, TP104: SOLDER GND; TestPoint_Pad_D4.0mm; MPN WIRE_PAD
TP103: SOLDER V5_EXT; TestPoint_Pad_D4.0mm; MPN WIRE_PAD
U101: TLV76750DRVR; WSON-6-1EP_2x2mm_P0.65mm_EP1x1.6mm_ThermalVias; MPN TLV76750DRVR
U102: TLV1117LV33DCYR; SOT-223-3_TabPin2; MPN TLV1117LV33DCYR

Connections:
GND: C101.2, C102.2, C103.2, C104.2, C105.2, J102.1, J104.1, J105.1, TP102.1, TP104.1, U101.3 (GND), U101.5 (GND), U101.7 (PAD), U102.1 (GND); also elsewhere on the board
V3P3: C104.1, C105.1, U102.2 (VO); also elsewhere on the board
V5_EXT: D102.2 (A), J103.1, TP103.1; also elsewhere on the board
V5_LDO: C102.1, D101.2 (A), U101.1 (OUT), U101.2 (SNS)
V5_LOGIC: C103.1, D101.1 (K), D102.1 (K), U102.3 (VI)
V7P4: C101.1, J101.1, J105.2, TP101.1, U101.4 (EN), U101.6 (IN); also elsewhere on the board

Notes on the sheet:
REGULATED INPUTS ONLY: 7.4 V UBEC / 5 V APM. NEVER connect 14-18S pack directly. Diodes feed LOGIC only.

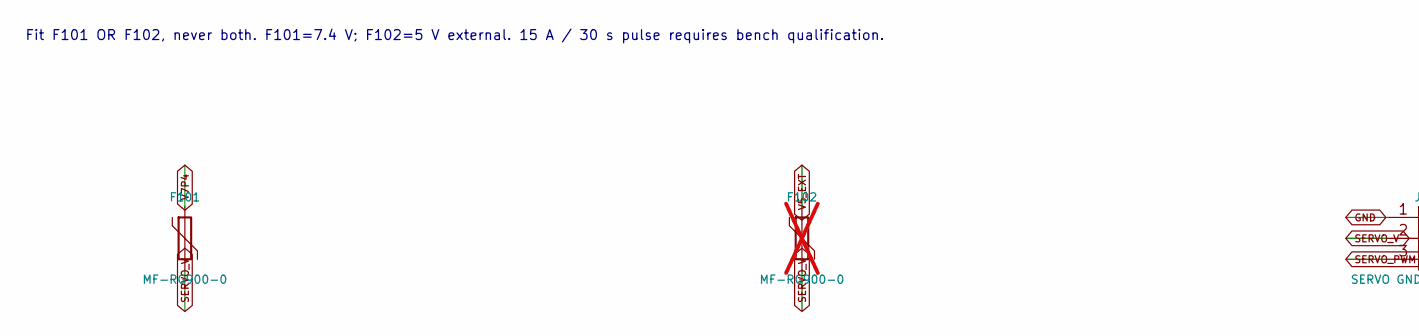
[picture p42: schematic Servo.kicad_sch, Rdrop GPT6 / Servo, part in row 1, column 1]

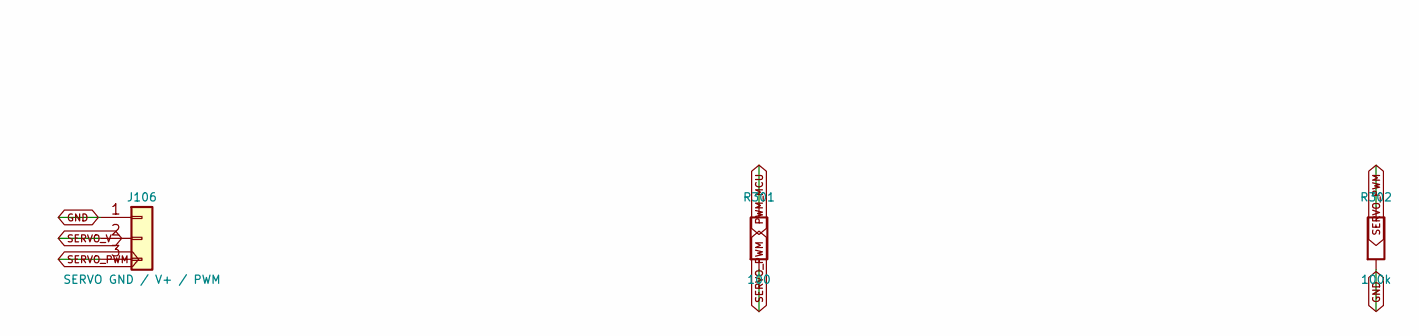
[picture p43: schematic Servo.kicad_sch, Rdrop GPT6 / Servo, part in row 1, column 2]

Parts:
F101: MF-RG900-0; Fuse_Bourns_MF-RG900; MPN MF-RG900-0
F102: MF-RG900-0; Fuse_Bourns_MF-RG900; MPN MF-RG900-0; not fitted
J106: SERVO GND / V+ / PWM; TerminalBlock_Phoenix_MKDS-3-3-5.08_1x03_P5.08mm_Horizontal; MPN 1711738
R301: 100; R_0603_1608Metric; MPN RC0603FR-07100RL
R302: 100k; R_0603_1608Metric; MPN RC0603FR-07100KL

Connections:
GND: J106.1, R302.2; also elsewhere on the board
PWM_MCU: R301.1; also elsewhere on the board
SERVO_PWM: J106.3, R301.2, R302.1
SERVO_V: F101.2, F102.2, J106.2
V5_EXT: F102.1; also elsewhere on the board
V7P4: F101.1; also elsewhere on the board

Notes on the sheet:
Fit F101 OR F102, never both. F101=7.4 V; F102=5 V external. 15 A / 30 s pulse requires bench qualification.

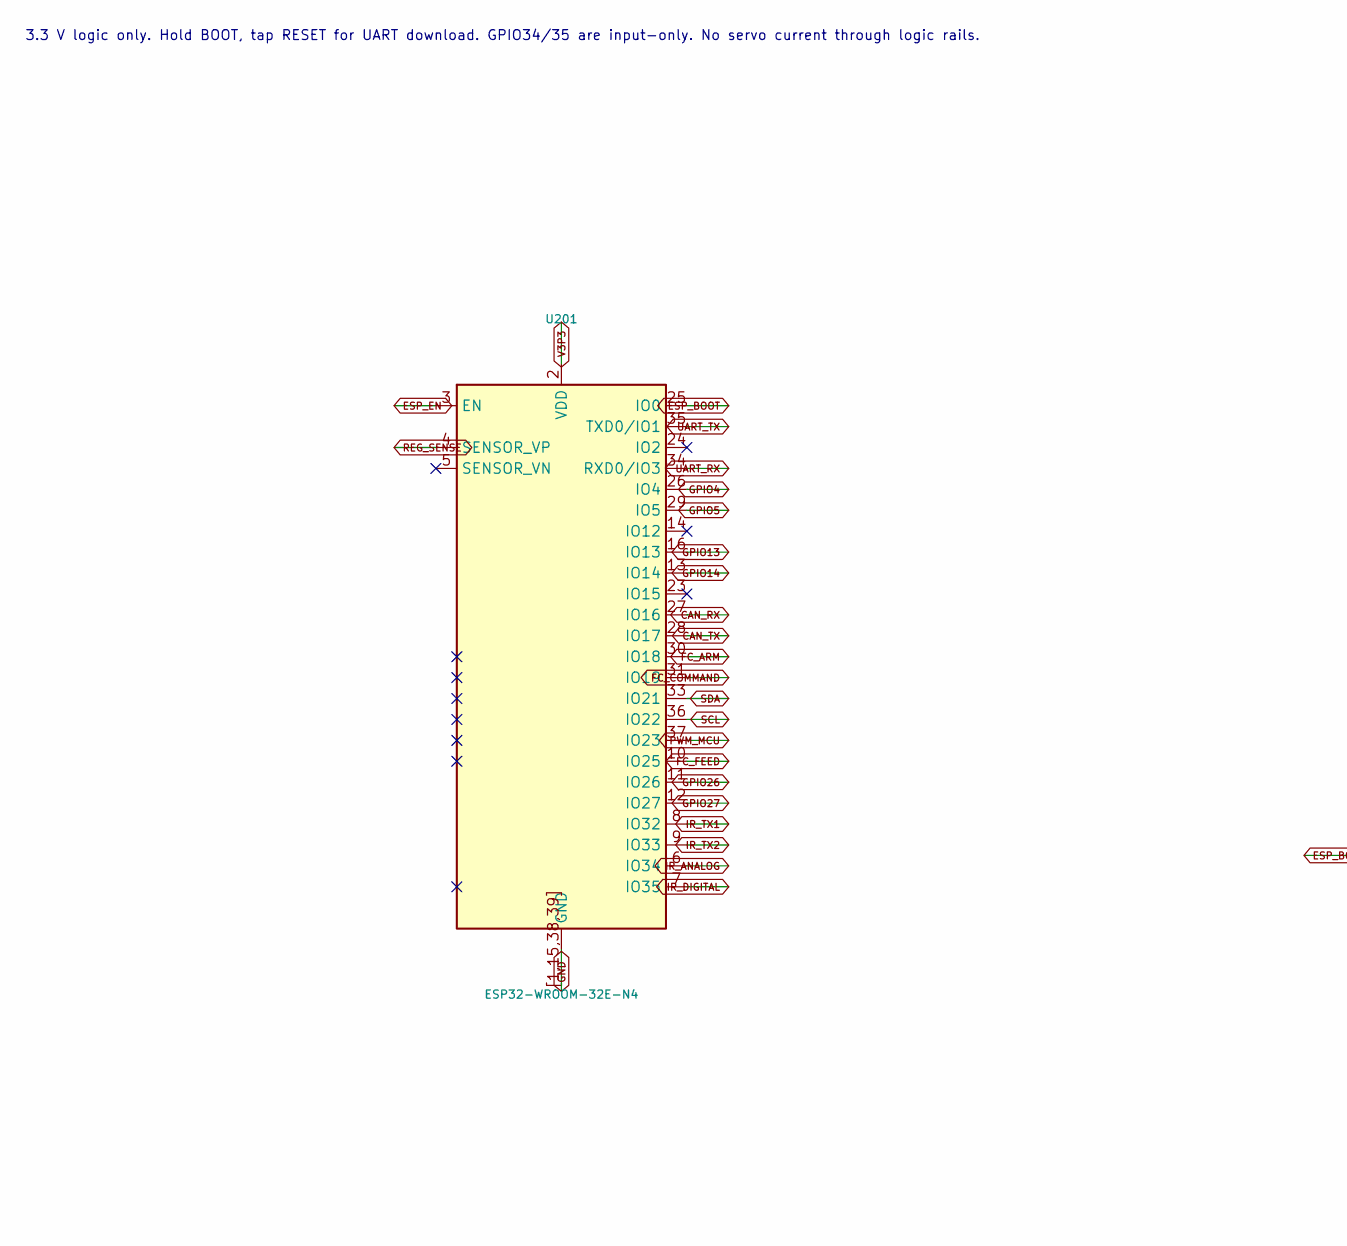
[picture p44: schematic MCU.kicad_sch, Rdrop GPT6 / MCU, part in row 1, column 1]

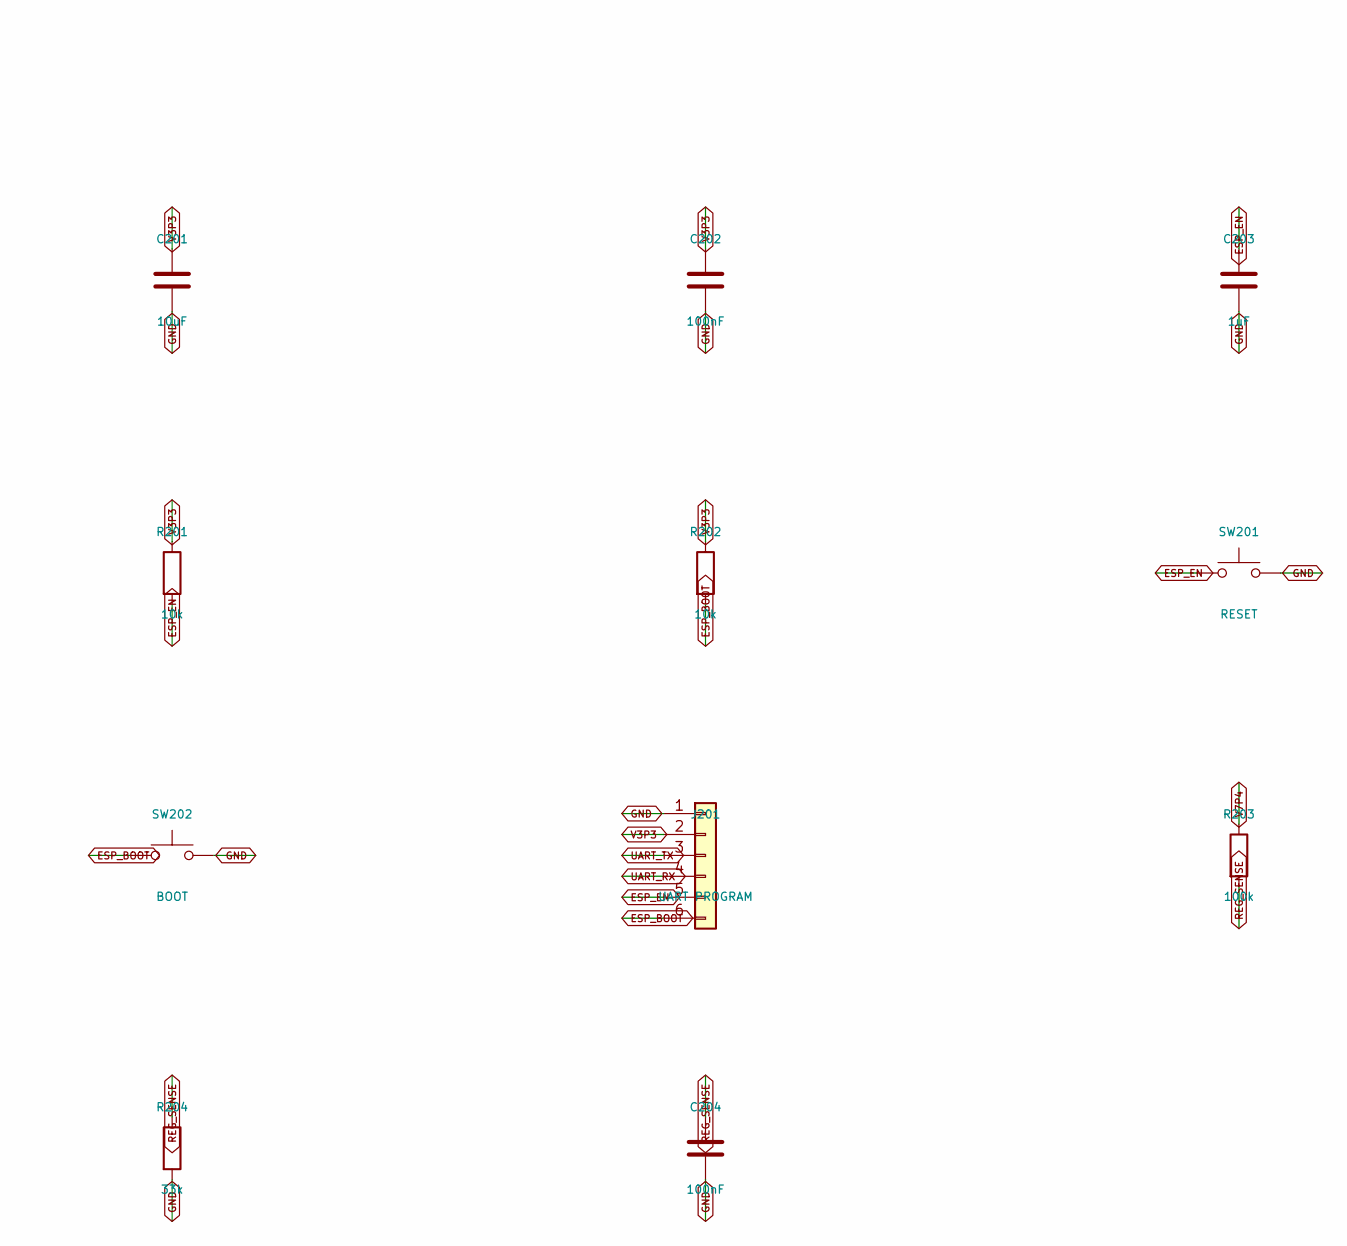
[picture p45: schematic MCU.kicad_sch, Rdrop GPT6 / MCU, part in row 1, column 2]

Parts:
C201: 10uF; C_0603_1608Metric; MPN GRM188R61C106KAALD
C202, C204: 100nF; C_0603_1608Metric; MPN GRM188R71H104KA93D
C203: 1uF; C_0603_1608Metric; MPN GRM188R61E105KA12D
J201: UART PROGRAM; PinHeader_1x06_P2.54mm_Vertical; MPN TSW-106-07-G-S
R201, R202: 10k; R_0603_1608Metric; MPN RC0603FR-0710KL
R203: 100k; R_0603_1608Metric; MPN RC0603FR-07100KL
R204: 33k; R_0603_1608Metric; MPN RC0603FR-0733KL
SW201: RESET; SW_SPST_TL3342; MPN TL3342F160QG
SW202: BOOT; SW_SPST_TL3342; MPN TL3342F160QG
U201: ESP32-WROOM-32E-N4; ESP32-WROOM-32E; MPN ESP32-WROOM-32E-N4

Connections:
CAN_RX: U201.27 (IO16); also elsewhere on the board
CAN_TX: U201.28 (IO17); also elsewhere on the board
ESP_BOOT: J201.6, R202.2, SW202.1, U201.25 (IO0)
ESP_EN: C203.1, J201.5, R201.2, SW201.1, U201.3 (EN)
FC_ARM: U201.30 (IO18); also elsewhere on the board
FC_COMMAND: U201.31 (IO19); also elsewhere on the board
FC_FEED: U201.10 (IO25); also elsewhere on the board
GND: C201.2, C202.2, C203.2, C204.2, J201.1, R204.2, SW201.2, SW202.2, U201.1, U201.15, U201.38, U201.39, U201.[1,15,38,39] (GND); also elsewhere on the board
GPIO4: U201.26 (IO4); also elsewhere on the board
GPIO5: U201.29 (IO5); also elsewhere on the board
GPIO13: U201.16 (IO13); also elsewhere on the board
GPIO14: U201.13 (IO14); also elsewhere on the board
GPIO26: U201.11 (IO26); also elsewhere on the board
GPIO27: U201.12 (IO27); also elsewhere on the board
IR_ANALOG: U201.6 (IO34); also elsewhere on the board
IR_DIGITAL: U201.7 (IO35); also elsewhere on the board
IR_TX1: U201.8 (IO32); also elsewhere on the board
IR_TX2: U201.9 (IO33); also elsewhere on the board
PWM_MCU: U201.37 (IO23); also elsewhere on the board
REG_SENSE: C204.1, R203.2, R204.1, U201.4 (SENSOR_VP); also elsewhere on the board
SCL: U201.36 (IO22); also elsewhere on the board
SDA: U201.33 (IO21); also elsewhere on the board
UART_RX: J201.4, U201.34 (RXD0/IO3); also elsewhere on the board
UART_TX: J201.3, U201.35 (TXD0/IO1); also elsewhere on the board
V3P3: C201.1, C202.1, J201.2, R201.1, R202.1, U201.2 (VDD); also elsewhere on the board
V7P4: R203.1; also elsewhere on the board

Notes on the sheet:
3.3 V logic only. Hold BOOT, tap RESET for UART download. GPIO34/35 are input-only. No servo current through logic rails.

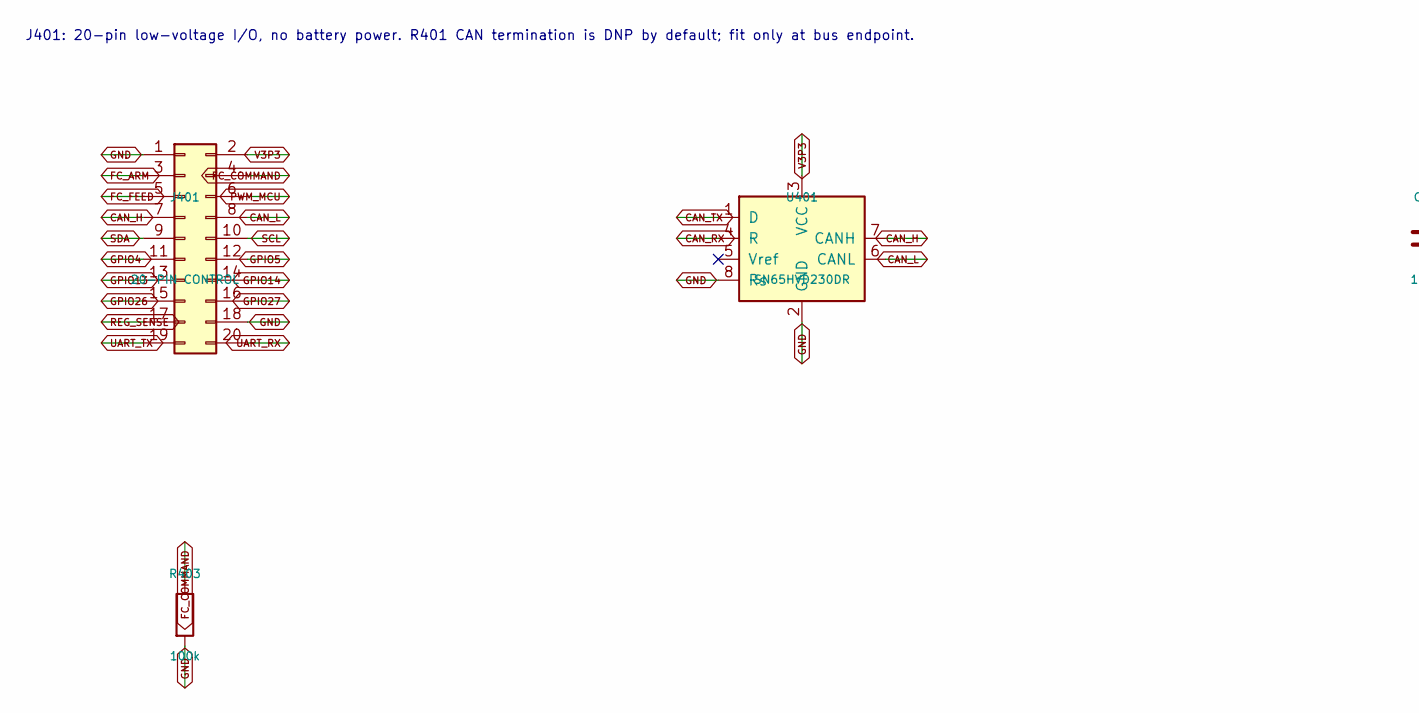
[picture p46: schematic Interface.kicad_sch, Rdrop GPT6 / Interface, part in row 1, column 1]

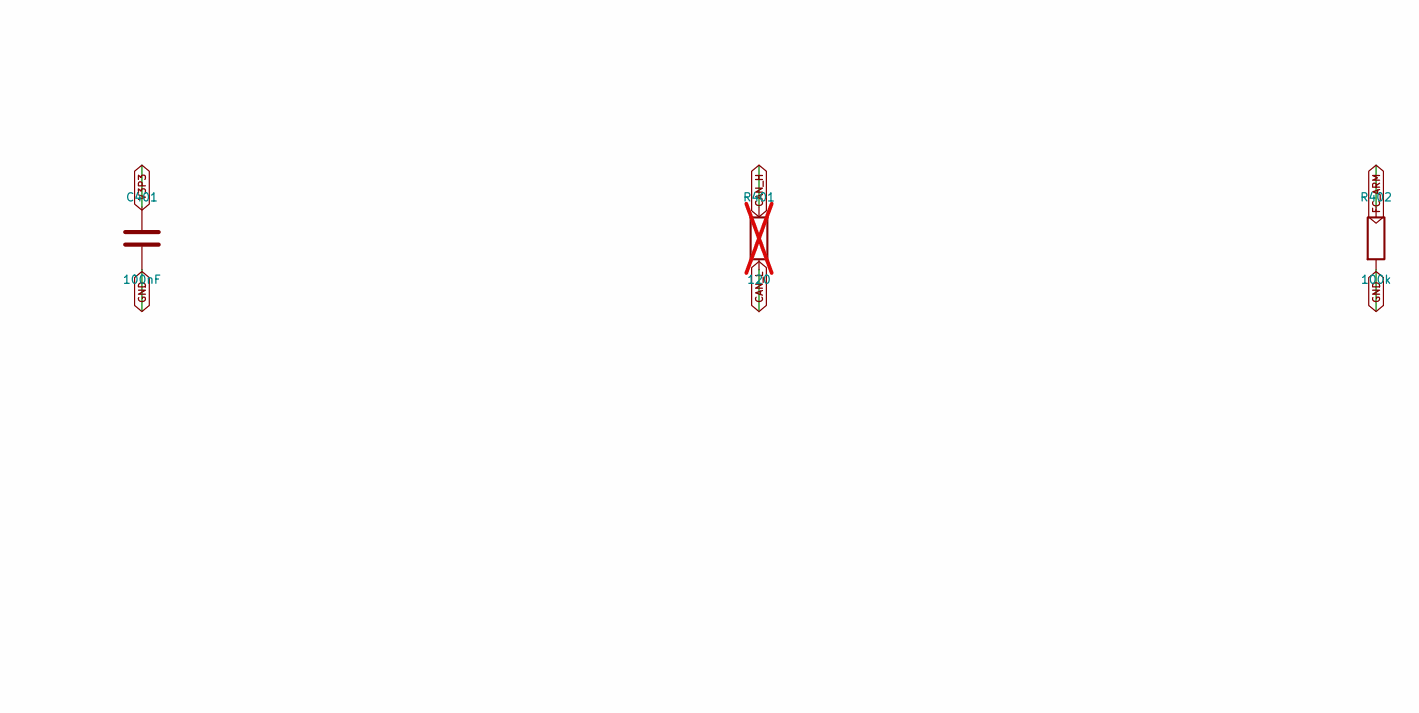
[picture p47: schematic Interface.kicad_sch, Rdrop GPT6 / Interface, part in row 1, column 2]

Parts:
C401: 100nF; C_0603_1608Metric; MPN GRM188R71H104KA93D
J401: 20-PIN CONTROL; PinHeader_2x10_P2.54mm_Vertical; MPN TSW-110-07-G-D
R401: 120; R_0603_1608Metric; MPN RC0603FR-07120RL; not fitted
R402, R403: 100k; R_0603_1608Metric; MPN RC0603FR-07100KL
U401: SN65HVD230DR; SOIC-8_3.9x4.9mm_P1.27mm; MPN SN65HVD230DR

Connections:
CAN_H: J401.7, R401.1, U401.7 (CANH)
CAN_L: J401.8, R401.2, U401.6 (CANL)
CAN_RX: U401.4 (R); also elsewhere on the board
CAN_TX: U401.1 (D); also elsewhere on the board
FC_ARM: J401.3, R402.1; also elsewhere on the board
FC_COMMAND: J401.4, R403.1; also elsewhere on the board
FC_FEED: J401.5; also elsewhere on the board
GND: C401.2, J401.1, J401.18, R402.2, R403.2, U401.2 (GND), U401.8 (Rs); also elsewhere on the board
GPIO4: J401.11; also elsewhere on the board
GPIO5: J401.12; also elsewhere on the board
GPIO13: J401.13; also elsewhere on the board
GPIO14: J401.14; also elsewhere on the board
GPIO26: J401.15; also elsewhere on the board
GPIO27: J401.16; also elsewhere on the board
PWM_MCU: J401.6; also elsewhere on the board
REG_SENSE: J401.17; also elsewhere on the board
SCL: J401.10; also elsewhere on the board
SDA: J401.9; also elsewhere on the board
UART_RX: J401.20; also elsewhere on the board
UART_TX: J401.19; also elsewhere on the board
V3P3: C401.1, J401.2, U401.3 (VCC); also elsewhere on the board

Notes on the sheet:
J401: 20-pin low-voltage I/O, no battery power. R401 CAN termination is DNP by default; fit only at bus endpoint.

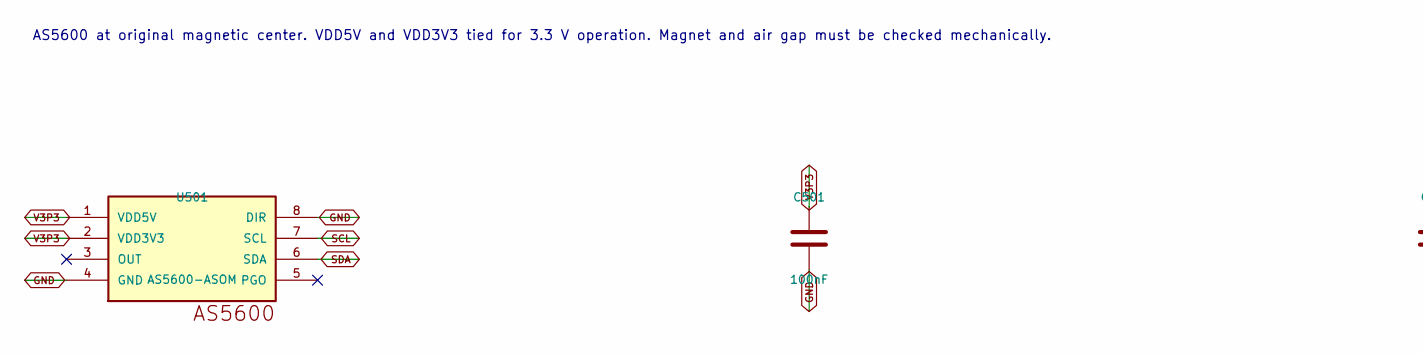
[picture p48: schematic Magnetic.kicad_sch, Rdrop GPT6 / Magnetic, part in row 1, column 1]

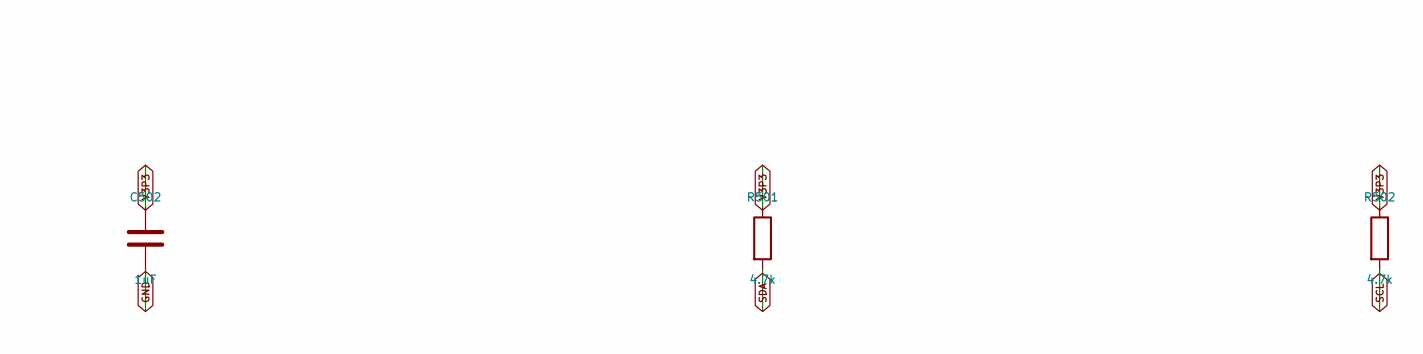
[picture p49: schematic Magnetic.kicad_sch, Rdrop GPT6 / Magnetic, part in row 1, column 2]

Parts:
C501: 100nF; C_0603_1608Metric; MPN GRM188R71H104KA93D
C502: 1uF; C_0603_1608Metric; MPN GRM188R61E105KA12D
R501, R502: 4.7k; R_0603_1608Metric; MPN RC0603FR-074K7L
U501: AS5600-ASOM; SOIC-8_3.9x4.9mm_P1.27mm; MPN AS5600-ASOM

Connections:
GND: C501.2, C502.2, U501.4 (GND), U501.8 (DIR); also elsewhere on the board
SCL: R502.2, U501.7 (SCL); also elsewhere on the board
SDA: R501.2, U501.6 (SDA); also elsewhere on the board
V3P3: C501.1, C502.1, R501.1, R502.1, U501.1 (VDD5V), U501.2 (VDD3V3); also elsewhere on the board

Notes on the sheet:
AS5600 at original magnetic center. VDD5V and VDD3V3 tied for 3.3 V operation. Magnet and air gap must be checked mechanically.

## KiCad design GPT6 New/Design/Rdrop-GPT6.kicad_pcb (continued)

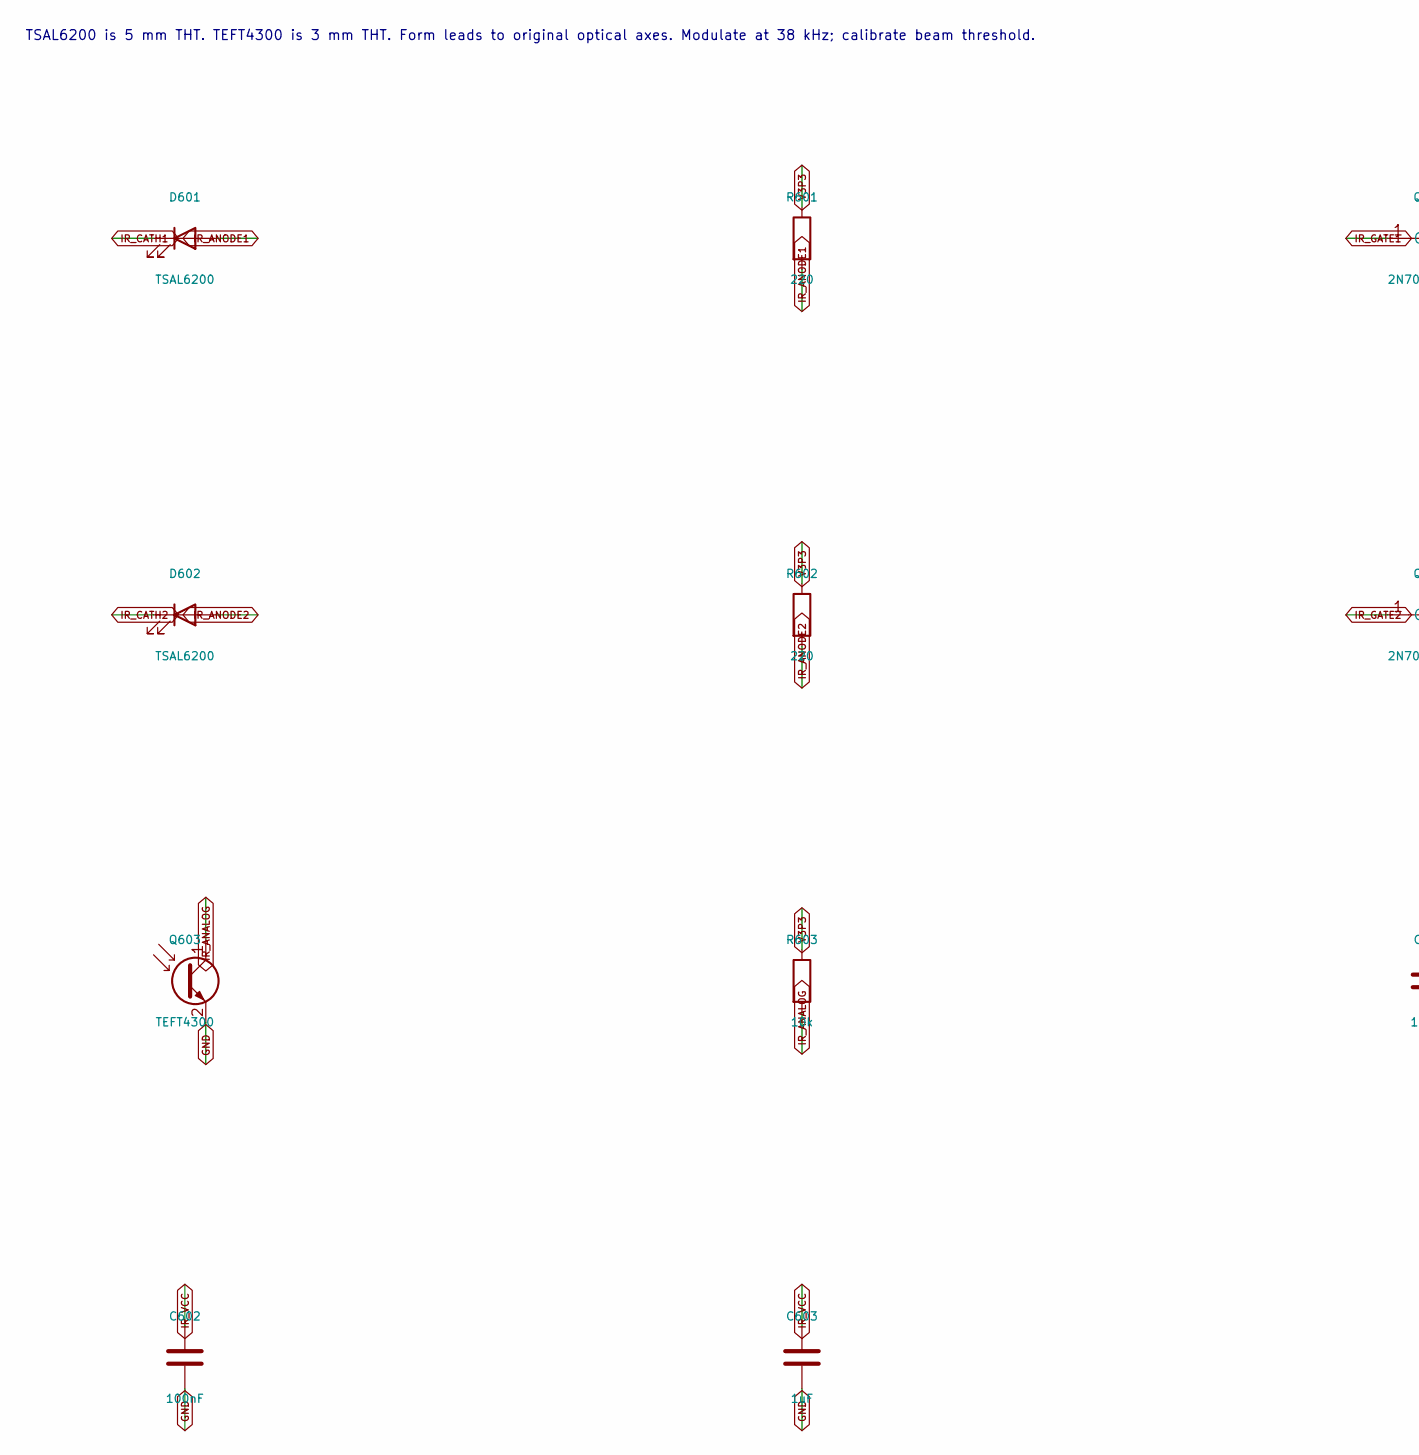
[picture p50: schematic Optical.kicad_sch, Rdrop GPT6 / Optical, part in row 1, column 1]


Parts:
C601, C602: 100nF; C_0603_1608Metric; MPN GRM188R71H104KA93D
C603: 1uF; C_0603_1608Metric; MPN GRM188R61E105KA12D
D601, D602: TSAL6200; LED_D5.0mm_Horizontal_O1.27mm_Z3.0mm; MPN TSAL6200
Q601, Q602: 2N7002P,215; SOT-23; MPN 2N7002P,215
Q603: TEFT4300; LED_D3.0mm_Horizontal_O1.27mm_Z2.0mm; MPN TEFT4300
R601, R602: 220; R_0603_1608Metric; MPN RC0603FR-07220RL
R603: 10k; R_0603_1608Metric; MPN RC0603FR-0710KL
R604, R611, R612: 100; R_0603_1608Metric; MPN RC0603FR-07100RL
R621, R622: 100k; R_0603_1608Metric; MPN RC0603FR-07100KL
U601: TSSP4038; Vishay_MOLD-3Pin; MPN TSSP4038

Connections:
GND: C601.2, C602.2, C603.2, Q601.2 (S), Q602.2 (S), Q603.2 (E), R621.2, R622.2, U601.2 (GND); also elsewhere on the board
IR_ANALOG: C601.1, Q603.1 (C), R603.2; also elsewhere on the board
IR_ANODE1: D601.2 (A), R601.2
IR_ANODE2: D602.2 (A), R602.2
IR_CATH1: D601.1 (K), Q601.3 (D)
IR_CATH2: D602.1 (K), Q602.3 (D)
IR_DIGITAL: U601.1 (OUT); also elsewhere on the board
IR_GATE1: Q601.1 (G), R611.2, R621.1
IR_GATE2: Q602.1 (G), R612.2, R622.1
IR_TX1: R611.1; also elsewhere on the board
IR_TX2: R612.1; also elsewhere on the board
IR_VCC: C602.1, C603.1, R604.2, U601.3 (Vs)
V3P3: R601.1, R602.1, R603.1, R604.1; also elsewhere on the board

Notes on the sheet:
TSAL6200 is 5 mm THT. TEFT4300 is 3 mm THT. Form leads to original optical axes. Modulate at 38 kHz; calibrate beam threshold.


Board: 2 copper layers, 189.5 x 79.7 mm, 69 parts (0 on the bottom side), 40 nets.
